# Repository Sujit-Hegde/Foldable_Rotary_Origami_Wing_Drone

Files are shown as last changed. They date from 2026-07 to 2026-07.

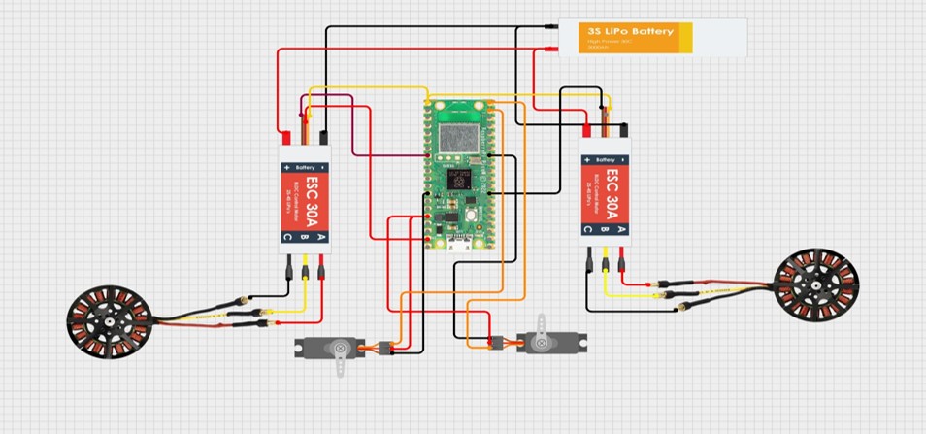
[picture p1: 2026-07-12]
Circuit Diagram.jpg

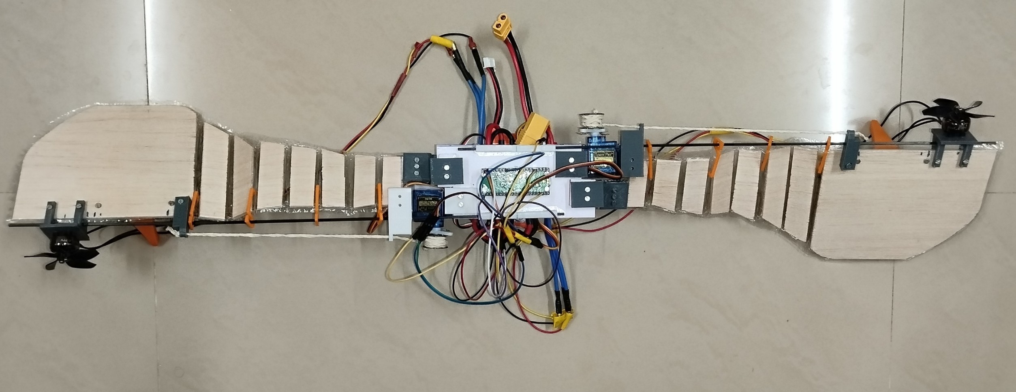
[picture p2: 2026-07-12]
FROW Picture.jpg

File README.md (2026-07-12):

# Foldable Rotary Origami Wing (FROW) Drone

A bio-inspired **Foldable Rotary Origami Wing (FROW) Drone** that combines the energy efficiency of a **monocopter** with an **origami-inspired morphing wing mechanism**. The drone actively changes its wingspan during operation using a servo-driven folding mechanism, enabling it to transition between efficient hovering and compact flight configurations suitable for navigating confined environments.

This project was developed as a **Bachelor of Engineering Final Year Project** in the Department of Electronics and Instrumentation Engineering, **Sri Jayachamarajendra College of Engineering (SJCE), JSS Science and Technology University, Mysuru**.

---

# Project Overview

Conventional quadcopters have a fixed geometry that limits their ability to fly through narrow passages such as pipelines, collapsed structures, and confined industrial environments.

The **Foldable Rotary Origami Wing (FROW) Drone** addresses this limitation by integrating an accordion-style origami wing capable of reducing its wingspan during operation. The platform adopts a **single-actuator monocopter configuration**, producing lift through a rotating wing while maintaining a lightweight and energy-efficient design.

The project combines:

- Bio-inspired aerodynamics
- Origami engineering
- Embedded control
- Wireless web-based control
- Mechanical morphing
- Raspberry Pi Pico W based control

---

# Features

- Active origami wing folding mechanism
- Approximately **40% wingspan reduction**
- Lightweight monocopter platform
- Raspberry Pi Pico W based controller
- Brushless DC motor propulsion
- Servo-controlled folding mechanism
- Wireless control through Wi-Fi
- React.js based dashboard
- Node.js backend server
- Adjustable motor pulse width
- Adjustable motor hold time
- Safe motor ramp-up and ramp-down sequence
- Remote operation through browser

---

# Project Demonstration

The complete web dashboard is deployed on **Vercel**.

### Live Website

https://trial-web-snowy.vercel.app

The dashboard allows users to:

- Turn system ON/OFF
- Fold the wings
- Reset the wings
- Configure maximum ESC pulse
- Configure motor hold time
- Send commands wirelessly to Raspberry Pi Pico W

---

# Repository Structure

```
Foldable_Rotary_Origami_Wing_Drone/
│
├── 3D Design/
│   ├── Servo Holder
│   ├── Wing Holder
│   ├── Guide Track
│   ├── Motor Mount
│   ├── Wing Hanger
│
├── backend/
│   ├── server.js
│   ├── package.json
│   ├── package-lock.json
│   └── .gitignore
│
├── trial-web/
│   ├── public/
│   ├── scripts/
│   ├── src/
│   ├── package.json
│   ├── package-lock.json
│   ├── README.md
│   └── .gitignore
│
├── main.py
│
├── FROW Report.pdf
│
└── README.md
```

---

# Repository Description

## 3D Design

This folder contains all CAD models and 3D printable structural components used in the drone.

The components include:

- Servo Holder
- Wing Holder
- Wing Hanger Supports
- Slider Mechanism
- Guide Track Endcaps
- Motor Holders
- Structural Mounts

These parts were designed to assemble the foldable origami wing mechanism while maintaining structural rigidity during high-speed rotation.

---

## backend

The backend is developed using **Node.js** and serves as the communication bridge between the web dashboard and the Raspberry Pi Pico W.

Functions include:

- Store current drone state
- Receive dashboard commands
- Provide REST API endpoints
- Synchronize motor commands
- Synchronize servo commands

Main file:

```
server.js
```

---

## trial-web

This folder contains the complete frontend application developed using **React.js**.

The dashboard provides:

- Power Toggle
- Fold Button
- Reset Button
- Hold Time Input
- Maximum Pulse Input
- Real-time communication with backend

The frontend is deployed on:

https://trial-web-snowy.vercel.app

---

## main.py

This file contains the **entire Python program executed on the Raspberry Pi Pico W**.

Unlike traditional embedded projects, **no firmware development framework is used**.

The Raspberry Pi Pico W directly executes this Python program to:

- Connect to Wi-Fi
- Read dashboard commands
- Control ESC
- Control Servo Motors
- Execute safe motor ramping
- Execute folding sequence
- Update backend state

Major functionalities include:

- Wi-Fi communication
- HTTP REST requests
- PWM generation
- Servo control
- ESC control
- Safety limits
- Motor ramp-up
- Motor ramp-down
- Automatic backend synchronization

---

## FROW Report.pdf

This document contains the complete technical documentation of the project.

The report describes every stage of development, from concept to prototype testing, including theoretical background, hardware implementation, software architecture, experimental results, and future improvements.

### Contents of the Report

### Chapter 1 – Introduction

Introduces the motivation behind the project, discusses the limitations of conventional UAVs, presents the concept of the Foldable Rotary Origami Wing (FROW) Drone, and explains the objectives, project overview, and report organization.

---

### Chapter 2 – Literature Review

Presents a comprehensive survey of research papers related to:

- Monocopters
- Bio-inspired UAVs
- Morphing drones
- Origami engineering
- Foldable aerial robots

The chapter also compares existing systems, identifies their limitations, and explains how the proposed FROW drone addresses these challenges.

---

### Chapter 3 – Methodology

Describes the complete design methodology of the project, including:

- Project objectives
- Bio-inspired aerodynamic concepts
- Origami engineering principles
- Rotating platform control theory
- System architecture
- Hardware block diagram
- Circuit diagram
- Prototype design
- Performance evaluation metrics

---

### Chapter 4 – Hardware Description

Explains the physical implementation of the drone.

Topics covered include:

- Design specifications
- Material selection
- 3D printed components
- Servo holder
- Wing hanger supports
- Motor mounts
- Guide track endcaps
- Wing holder
- Fabrication parameters
- Hardware integration

This chapter describes the complete construction and assembly of the FROW prototype.

---

### Chapter 5 – Software Description

Describes the complete software architecture of the system.

It includes:

- Dashboard implementation
- User Interface
- Backend communication
- Python control program
- Control logic
- Safety mechanisms
- Wireless communication
- System workflow

The software enables real-time wireless control of the drone through a web browser.

---

### Chapter 6 – Results and Discussion

Presents the experimental evaluation of the developed prototype.

The chapter discusses:

- Ground testing
- Lift-off experiments
- Folding mechanism performance
- Mechanical observations
- Rotational behavior
- Experimental results
- Performance analysis

The obtained results validate the effectiveness of the foldable monocopter concept.

---

### Chapter 7 – Conclusion and Future Work

Summarizes the overall achievements of the project.

This chapter discusses:

- Project conclusions
- Advantages
- Current limitations
- Practical applications
- Future enhancements

Potential future improvements include autonomous navigation, obstacle detection, advanced stabilization algorithms, and improved flight control.

---

The report also contains:

- Abstract
- Acknowledgements
- List of Figures
- List of Tables
- List of Abbreviations
- References
- Appendix

---

# Hardware Used

- Raspberry Pi Pico W - https://robu.in/product/raspberry-pi-pico-w/
- Brushless DC Motor - https://robu.in/product/flywoo-co-brand-nin-1404-v2-dave-c-fpv-fpv-motortitan-4850kv/
- Electronic Speed Controller (ESC) - https://robu.in/product/30a-bldc-esc-electronic-speed-controller/
- Servo Motor - https://robu.in/product/towerpro-sg90-continuous-rotation-360-degree-servo-motor/
- Li-Po Battery - https://robu.in/product/orange-11-1v-1500mah-3s-40c-lipo-battery-pack-xt60-connector/
- Carbon Fiber Rods - https://robu.in/product/pultruded-square-carbon-hollow-fiber-tube-22mmod-1mmid-400mml-2pcs/
- Balsa Wood - https://www.rcdhamaka.com/product/balsa-sheet-2mm-x-100mm-x-1000mm/
- Polymer Lamination Film - https://www.flightmode.co.in/products/transparent-clear-covering-film-1-meter

---

# Software Used

Frontend

- React.js

Backend

- Node.js
- Express.js

Controller

- Python (Raspberry Pi Pico W)

Communication

- HTTP REST API
- JSON

Development Tools

- Thonny (For Python coding)
- Visual Studio Code

---

# Working Principle

1. User opens the web dashboard.
2. Commands are sent to the backend server.
3. Raspberry Pi Pico W periodically fetches the current state.
4. Python program interprets received commands.
5. Servo motors fold or unfold the origami wings.
6. ESC generates PWM signals to control the BLDC motor.
7. Motor speed gradually increases and decreases for safe operation.
8. Backend updates the current drone status.

---

# Future Improvements

- Closed-loop flight stabilization
- IMU integration
- PID-based control
- LiDAR obstacle detection
- Camera-based navigation
- Autonomous flight
- Waypoint navigation
- UDP communication
- Telemetry support
- Mobile application
- Flight data logging

---

# Demo Video

Link - https://drive.google.com/drive/folders/1Tsia0g6oVi0r_j1Qm1odxm1_M7kFNv6A?usp=sharing

---

# Authors

**Sujit Satish Hegde**

Department of Electronics and Instrumentation Engineering

Sri Jayachamarajendra College of Engineering

JSS Science and Technology University

---

**Virupaksha A. Alur**

Department of Electronics and Instrumentation Engineering

Sri Jayachamarajendra College of Engineering

JSS Science and Technology University

---

**Abhishek K. T**

Department of Electronics and Instrumentation Engineering

Sri Jayachamarajendra College of Engineering

JSS Science and Technology University

---

# License

This repository is intended for **academic and educational purposes**.

Feel free to use the project for learning and research while providing appropriate credit to the authors.

---

⭐ If you found this project useful, consider giving this repository a star.

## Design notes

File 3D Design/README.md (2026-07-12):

These are the 3D Design which are required for the Foldable Rotary Origami Wing (Frow) Drone

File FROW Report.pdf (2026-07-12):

### JSS Mahavidyapeetha JSS SCIENCE AND TECHNOLOGY UNIVERSITY SRI JAYCHAMRAJENDRA COLLEGE OF ENGINEERING JSS Technical Institutions’ Campus, Mysuru – 570006

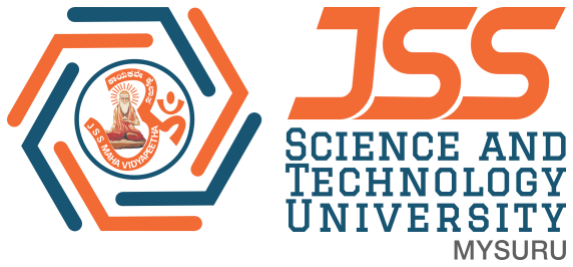
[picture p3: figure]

## FOLDABLE ROTARY ORIGAMI WING (FROW) DRONE

### Thesis submitted in partial fulfillment of curriculum prescribed for the award of the degree of

### BACHELOR OF ENGINEERING

IN

### ELECTRONICS AND INSTRUMENTATION ENGINEERING

by

## Sujit Satish Hegde

(02JST22UEI052)

## Virupaksha A Alur

(02JST22UEI059)

## Abhishek K T

(02JST23UEI401)

### Under the Guidance of

Dr. SUSHMA T
Assistant Professor,

### Department of Electronics and Instrumentation Engineering

SJCE, JSS STU, Mysuru.

DEPARTMENT OF ELECTRONICS AND INSTRUMENTATION ENGINEERING

May 2026

JSS MAHAVIDYAPEETHA
JSS SCIENCE AND TECHNOLOGY UNIVERSITY

## SRI JAYACHAMARAJENDRA COLLEGE OF ENGINEERING

- Constituent College of JSS Science and Technology University
- Approved by A.I.C.T.E
- Governed by the Grant-in-Aid Rules of Government of Karnataka
- NAAC Accredited

## CERTIFICATE

This is to certify that the work entitled “FOLDABLE ROTATRY ORIGAMI WING

(FROW) DRONE” is a bonafied work carried out by Sujit Satish Hegde (02JST22UEI052),

Virupaksha A Alur (02JST22UEI059) and Abhishek K T (02JST23UEI401) in Partial

fulfillment for the award of the Degree of Bachelor of Engineering in Electronics and

Instrumentation of Sri Jayachamarajendra College of Engineering, JSS Science and

Technology University, Mysuru, during the year 2025-26. It is certified that all corrections /

suggestions indicated during CIE have been incorporated in the report. The project report

has been approved as it satisfies the academic requirements in respect of project work

prescribed for the Bachelor of Engineering degree.

Dr. Sushma T
Assistant Professor
Dept. of E&I
SJCE, JSS STU, Mysuru.

Dr. Mallikarjunaswamy M S
Head of the Department
Dept. of E&I
SJCE, JSS STU, Mysuru.
Examiners: 1. |
Date: | 2. |
Place: Mysuru | 3. |

DECLARATION

We hereby declare that the project entitled “Foldable Rotary Origami Wing

(FROW) Drone” has been carried out by us as a part of our undergraduate studies,

under the guidance of Dr. Sushma T, Assistant Professor, Department of

Electronics and Instrumentation, Sri Jayachamarajendra College of Engineering,

JSS Science and Technology University, Mysuru.

This work is submitted in partial fulfilment of the requirements for the award of

the Bachelor’s Degree in Electronics and Instrumentation Engineering at Sri

Jayachamarajendra College of Engineering, JSS Science and Technology

University, Mysuru, during the academic year 2025-26

We further declare that this project work is original and has been carried out

independently by us. The content of this report has not been submitted, either in part or

in full, to any other university or institution for the award of any degree or diploma.

Date:

Place: Mysuru | Sujit Satish Hegde
| 02JST22UEI052

Virupaksha A Alur

02JST22UEI059

Abhishek K T

02JST23UEI401

i

## ABSTRACT

The fast development and miniaturization of electronics have contributed significantly

to the development of MAVs that are applied in vital tasks such as indoor surveillance,

search & rescue missions, and structural inspection operations. However, despite their

high maneuverability, conventional quadrotors are characterized by low power

efficiency owing to small rotor diameters and a large body that cannot fit into enclosed

areas. In addressing this challenge, the present project proposes the use of a FROW

drone, which combines the advantages of a highly efficient rotary wing aircraft design

and the flexibility offered by the origami concept.

Inspired by the movement of the samara seed as well as the ability of birds to fold their

wings while maneuvering through tight spaces, the FROW drone incorporates a

spinning wing for generating lift across the entire wing surface. The key breakthrough

comes from incorporating an accordion-like folding wing system in which the wingspan

can be actively contracted or expanded in mid-flight. This feature permits the drone to

switch between flight modes, from a wider span ideal for hovering to a more compact

form intended for accessing tight passages and pipelines.

The structure of the drone consists of flexible balsa wood pieces joined with sheets of

thin plastic. This allows the wing to maintain structural rigidity during high-speed

rotation while still be able to bend so that the folds can function. An automatic string

reel is used to manipulate the accordion fold pattern, thereby reducing the area occupied

by the aircraft by about 39% to 40% mid-flight. This advantage puts the UAV ahead of

traditional drones which may be less maneuverable.

Moreover, attitude stabilization control has been integrated into the system to mitigate

the unwanted angular rates of motion that result when the moment of inertia of the

aircraft varies with the folding of the wings. Through the use of the internal inertial

sensors, the stability of the UAV is assured despite the drastic changes in the flight

dynamics of the aircraft.

The effectiveness of the drone was tested extensively, with emphasis on its capability

to take off from the ground and demonstrate the mechanical folding process. The results

suggest that the drone is successful in meeting its objective of reducing wingspan while

still having enough lift to fly. The system achieved a flight efficiency of approximately

ii

7.1 g/W, outperforming traditional multirotor drones such as the Crazyflie, which flies

at an average of 4.3 g/W.

In addition to the morphing dynamics, the mechanical construction of the FROW drone

also relies on modularity and economy of materials. Specifically, components such as

balsa wood and carbon fiber are employed in order to build a highly efficient yet

lightweight structure. The particular design of the wing components involves an

accordion-folding design that uses guide rails and hangers to allow the wings to

contract. Hardware in this case is coupled with the Raspberry Pi Pico controller which

collects live readings from a three-axis magnetic field sensor and inertial sensors to

maintain the stability of the device in both vertical and horizontal directions. Through

balancing centrifugal forces produced while rotating and mechanical tensions created

through servos, it is possible to sustain aerodynamic lift while reducing the size of the

wings.

The successful realization of the folding rotary-wing concept is thus a key proof-of-

concept step toward the development of the next wave of transformable aerial robots.

Overcoming the constraints of limited footprints associated with conventional UAVs,

while retaining the energy efficiency of a monocopter, offers great opportunities to

explore new ways of using drones in situations where only small UAVs would fit in.

Utilizing the potential of paper engineering in order to fabricate intricate,

multifunctional geometries enables the creation of robots which are both portable and

deployable on short notice in time-critical situations.

## iii

## ACKNOWLEDGEMENTS

With profound pleasure and immense satisfaction, we submit our project entitled –

"FOLDABLE ROTARY ORIGAMI WING(FROW) DRONE ".

We take the opportunity to express our sincere gratitude to the following persons

without whom this project would not have been possible and whose firm belief in our

capabilities and moral support in bringing out our full potential towards the forefront

has played a major role in each and every step of our endeavor towards success.

We express our deep sense of gratitude to our guide Dr. Sushma T, Assistant Professor,

Department of Electronics and Instrumentation Engineering, Sri Jayachamarajendra

College of Engineering, JSS Science and Technology University, Mysuru for the

valuable help and guidance. We are thankful for the encouragement given in completing

the project.

We would like to express our sincere thanks to our project coordinators Dr. Babu K S,

Ms. Anusha M U, Assistant Professors, Department of Electronics and Instrumentation

Engineering, Sri Jayachamarajendra College of Engineering, JSS Science and

Technology University, Mysuru for assisting us in all the activities involved in

completing the project.

We would like to express our sincere thanks to Dr. Mallikarjunaswamy M S,

Associate Professor and Head, Department of Electronics & Instrumentation

Engineering, Sri Jayachamarajendra College of Engineering, JSS Science and

Technology University. Mysuru, for permitting us to utilize all the facilities of the

department.

We would like to express our sincere thanks to our respected Principal, Dr. C Nataraju

for providing us an excellent academic atmosphere and encouragement in the

university.

We would like to thank Mr. Soorya Swamy Student from Department of Mechanical

Engineering and Aero JC for helping us with the lamination of the wings and the design

of the 3D model. We are also thankful to all the teaching and non-teaching staff

members of our department for their kind cooperation and help.

iv

## CONTENTS

Sl. No. | Content | Page No.
| | Abstract | i
| | Acknowledgement | iii
| | Contents | iv
| | List of Figures | vi
| | List of Tables | vi
| | List of Abbreviations | vii
1. | | INTRODUCTION | 1
| 1.1 | Motivation | 2
| 1.2 | Objectives | 3
| 1.3 | Overview of the Project | 4
| 1.4 | Organization of the Report | 5
2. | | LITERATURE REVIEW | 7
| 2.1 | Comparison of Existing System | 11
3. | | METHODOLOGY | 14
| 3.1 | Objectives | 14
| 3.2 | Bio-Inspired Aerodynamics | 15
| 3.3 | Origami Engineering Principles | 15
| 3.4 | Control Theory for Rotating Platforms | 16
| 3.5 | System Architecture and Design | 17
| 3.6 | Evaluation Metrics | 20
4. | | HARDWARE DESCRIPTION | 21
| 4.1 | Design Specifications and Materials | 21
| 4.2 | Hardware and 3D Components | 22
| 4.3 | 3D-Printed Structural Components | 22
| 4.4 | Fabrication Parameters | 26
| 4.5 | Hardware Integration | 26
5. | | SOFTWARE DESCRIPTION | 27
| 5.1 | Software Implementation and Interfacing | 27
| 5.2 | Dashboard and User Interface | 27
| 5.3 | Control Logic and Safety Features | 29

v

| 5.4 | Control Flow Diagram | 30
| 5.5 | Control Firmware Development | 30
6. | | RESULTS AND DISCUSSION | 32
| 6.1 | Test Results | 32
| 6.2 | Discussion | 34
7. | | CONCLUSION AND FUTURE WORK | 35
| 7.1 | Conclusion | 35
| 7.2 | Advantages | 36
| 7.3 | Limitations | 36
| 7.4 | Applications | 37
| 7.5 | Future Enhancements | 38
| | REFERENCES | 39
| | APPENDIX | 41

vi

## LIST OF FIGURES

Figure No. | Name | Page No.
3.1 | Block Diagram of the Proposed FROW System | 17
3.2 | Circuit Diagram | 18
3.3 | Prototype Design | 19
3.4 | Design Output of FROW | 19
4.1 | Servo Holder | 23
4.2 | Wing Hanger Supports and Slider | 23
4.3 | Leading Edge Motor Mount | 24
4.4 | Guide Track Endcap | 24
4.5 | Wing Holder | 25
4.6 | Leading-Edge Motor Holder | 25
5.1 | Dashboard and User Interface – I | 28
5.2 | Dashboard and User Interface – II | 29
5.3 | Control Flow Diagram | 30
5.4 | Main Logic Code Snippet | 31
6.1 | Unfolded FROW Rotation | 33
6.2 | Folded FROW Rotation | 33

## LIST OF TABLES

Table No. | Name | Page No.
2.1 | Comparison of Existing Systems | 11
4.1 | Fabrication Parameters | 26

## vii

## LIST OF ABBREVIATIONS

Abbreviation | Full Form
UAV | Unmanned Aerial Vehicle
MAV | Micro Aerial Vehicle
FROW | Foldable Rotary Origami Wing
ESC | Electronic Speed Controller
BLDC | Brushless DC
PWM | Pulse Width Modulation
FPV | First Person View
PLA | Polylactic Acid
FDM | Fused Deposition Modeling
GUI | Graphical User Interface
HTTP | Hypertext Transfer Protocol
REST API | Representational State Transfer Application Programming Interface
JSON | JavaScript Object Notation
IMU | Inertial Measurement Unit
GPIO | General Purpose Input/Output
PDB | Power Distribution Board
KV | RPM per Volt Rating of BLDC Motor
PID | Proportional Integral Derivative
UI | User Interface
Li-Po | Lithium Polymer

## CHAPTER 1

## INTRODUCTION

Drones or Unmanned Aerial Vehicles (UAVs) have evolved from specialized devices

used by the military to vital tools for civilians in numerous applications. They are

currently utilized for various purposes, such as mapping the environment, surveillance

in cities, inspecting infrastructure, and conducting rescue missions during emergencies.

Their importance is mainly attributed to their capability of operating in environments

that can be dangerous, distant, or constrained, making them inaccessible to humans.

With an increase in the need for adaptable unmanned aerial robots, studies have

concentrated on improving maneuverability in complex settings.

Even though they are common, the basic design of a multicopter, particularly a

quadcopter, still has fundamental constraints. Quadcopters are highly agile aircraft that

can take off vertically but create thrust using small propellers, which according to

momentum theory, is an inefficient way of generating thrust while hovering as opposed

to large rotor areas. Additionally, traditional drones have a fixed geometric

configuration, meaning that their wingspan and arm span cannot change when in the

air. This limits their ability to fly through confined spaces like collapsed buildings or

pipelines.

A solution for overcoming the limitations discussed above comes from the development

of the Foldable Rotary Origami Wing (FROW) drone, a bio-inspired aerial system. In

this regard, one can point out that the main inspiration is derived from the botanic

structure of the samara seed, also known as a “helicopter seed,” which performs the

process of autorotation to land. The monocopter concept, when a single rotating wing

is used for generating lift across the entire wing surface, allows for the realization of

increased flight efficiency compared to conventional drones with multiple wings. This

increased efficiency, however, will be complemented by the concept of “active

morphology” similar to birds such as Peregrine Falcons, which retract their wings for

fast diving or tight maneuvers.

The distinctive feature of the FROW drone is the use of an innovative folding wing

design similar to an accordion. While the earlier models could fold their wings only

with some external help, the FROW model can fold and unfold the wings independently during flight. The wings are made of light balsa wood panels covered with a thin layer

of plastic sheet to achieve sufficient rigidity during fast spinning and facilitate folding

according to the mountains and valleys. In addition, the folding mechanism helps the

drone achieve up to 40% reduction in overall size in flight.

The control of a rotorcraft that transforms during flight poses an entirely different

challenge to engineers due to the shifting center of mass and moment of inertia caused

by changing shapes in mid-air. In order to achieve stability in flight, the proposed

project adopts a control system composed of a Raspberry Pi Pico controller, together

with a customized attitude stabilization algorithm and a cyclic thrust algorithm. Unlike

the use of a swashplate mechanism, the direction control is done through the use of

pulse modulation on the motor thrusts at specific points within the rotation period.

The scope of this work covers all aspects of the development process of the FROW

drone, including designing the drone in CAD programs and analyzing its structural

properties, extending to the fabrication and testing of the prototype on the ground. The

successful lifting of the drone, and its capability to reduce its wingspan, is considered

a proof of concept for transformable drones that are capable of combining efficiency

and agility without compromising one for the other.

### 1.1 MOTIVATION

The primary inspiration behind the creation of the Foldable Rotary Origami Wing

(FROW) drone is rooted in the pressing requirement for highly adaptable drones that

can fly in challenging environments. Standard drones, especially quadrotors, have a

fixed structure that cannot allow them to move through confined spaces smaller than

the drone’s body frame. In cases where drones are used to perform tasks like search and

rescue missions in rubble or inspect pipelines, there is a practical requirement for the

drone to be able to change its structure while in flight.

In addition, existing drones have a tendency to make compromises between efficiency

and maneuverability. The larger span rotors generate better lift and efficiency but are

hard to navigate around obstacles, whereas smaller drones cannot retain their batteries'

performance or payload. This problem has been solved by nature using various

biological strategies, such as the samara seeds' autorotation to conserve energy and the

birds' wing tucking ability for maneuverability around trees and during rapid descents.

Combining these two biological concepts, this project attempts to develop an aircraft

that takes advantage of both namely, high-efficiency monocopters and high

maneuverability morphing aircraft.

Another important factor which may contribute to conducting this research is the

opportunity to increase the stealth capability of the drone. In the process of

implementing modern surveillance missions, the reduced visibility of the drone may

play a significant role. With the help of folding, the FROW drone can assume a "stealth"

configuration which will ensure its ability to conduct missions without being detected

by the enemy or approaching some potentially dangerous zones. The stability achieved

due to the samara-like autorotation provides an additional safety feature since the

aircraft will always have the ability to land softly despite a complete loss of power.

Lastly, the project is driven by the need for improvement of unconventional flight

control systems. It involves creating a system that will remain stable when both the

moment of inertia and the aerodynamic center are constantly changing. Using a control

system based on Raspberry Pi Pico and implementing cyclic thrust control algorithms,

it will become possible to prove that even a vehicle of an irregular shape can be

successfully managed using readily available standard computer equipment. In the end,

FROW drone will serve as a concept of a new kind of robust MAVs that are capable of

adapting to their surroundings physically.

### 1.2 OBJECTIVES

The main aim of this project is to construct a monocopter aerial vehicle that includes

morphing origami wings able to contract/extend the wingspan mid-flight.

To realize this general aim, the project intends to reach the following particular goals:

- Development of an Accordion Origami Wing: Design a light-weight balsa wood

and thin laminate wing having rigid structure but capable of reducing footprint area by

contracting the wing panels mid-flight.

- Creation of an Active Actuation System: Design an actuator mechanism to control

the contraction and extension of the wing panels during flight using strings operated by

a servo system.

- Application of an Effective Control Architecture: Apply the Raspberry Pi Pico W

microcontroller board to stabilize the drone, interface sensors, and perform shape

change operations without disturbing the balance of rotation.

- Determination of Steady Flight Strategies: Design custom stabilization algorithms

to maintain flight stability and implement cyclic thrust approach to steer the vehicle.

- Flying and Morphing Capability Testing: Perform tests for assessing the flying

ability of the drone by generating enough aerodynamic lift, as well as the capability to

actively morph the wing.

- Maneuvering Performance Verification: Assess the possibility for the drone to fly

in confined spaces where its reduced wingspan is needed.

### 1.3 OVERVIEW OF THE PROJECT

In this project, the complete development of the Foldable Rotary Origami Wing

(FROW) is discussed, which is a micro aerial vehicle capable of having high efficiency

and structure change during flight. The FROW platform is created as a monocopter,

based on the idea of autorotation of samara seeds that use a single rotating wing to

produce lift along the entire wing span. In order to be able to vary the wingspan and

thereby switch between modes of flight with high efficiency and maneuvers, folding

has been incorporated into the design through origami.

The project's workflow will begin with the mechanical design of a wing, which will be

constructed using thin panels made of balsa wood and polymer. The panels will be fitted

together using an origami-inspired foldable structure that will enable folding the wing

down along pre-determined creases. To drive the process of folding the wing down, the

mechanical force will be supplied by the servo-controlled string winding system placed

at the center hub, whereas centrifugal forces will be used to unfold the wing.

The design of the control system involves the use of the Raspberry Pi Pico W

microcontroller. It receives the real-time input from the gyroscope and other inertial

devices and ensures balance within the frame of reference despite the constant rotation.

One important aspect of the software program is that of cyclic control, whereby the

thrust from the motor pulses at certain angles to control the angle of attack for both

pitch and roll of the drone.

The last stage includes hardware integration and experimentation. The drone will be

built using high KV FPV motors, ESCs (electronic speed controllers), and a high

discharge Li-Po battery in order to ensure sufficient weight to thrust ratio.

Experimentation will be carried out to confirm the structural integrity of the folding

operation as well as the performance of the stability algorithms. Through testing, it will

be demonstrated that the drone is capable of lifting itself and reducing its size by about

40%.

### 1.4 ORGANIZATION OF THE REPORT

This report is organized into five comprehensive chapters, each addressing specific

aspects of the project to ensure clarity and logical flow.

Chapter 1 sheds light on the importance of innovative UAV designs and draws attention

toward the significance of bioinspired unmanned aerial robotics in present times. The

chapter discusses the need for developing morphing drones, states the research goals,

gives an introduction to the FROW drone design and explains how the research attempts

to satisfy the demands of flight efficiency and spatial agility.

Chapter 2 focuses on the existing works done on foldable unmanned aerial vehicles and

morphing drones. The chapter highlights the inadequacies in existing quadcopter

designs, origami inspired wings, and different in-flight morphing techniques such as

active morphing using servos and passive morphing through centrifugal forces. The

chapter provides insights into the areas where the current fixed footprint drones fall

short in order to justify the adoption of foldable monocopter drones.

In chapter 3, the overall process adopted throughout the project is discussed in depth.

This includes the mechanical designing of the folding wing panels, the incorporation of

the servo-based folding mechanism, selection of the propulsion system, and designing

the control structure using Raspberry Pi Pico microcontroller. In other words, in this

chapter, we provide the comprehensive discussion on all the building blocks that form

the complete flying device.

In Chapter 4, the process of actual construction of the prototype is outlined. The

software environment along with its stabilization algorithms and cyclic thrust operation

is discussed along with its hardware design. This chapter also describes the process of

testing the prototype on the ground and the performance of the aircraft during its lift-off process. The results pertaining to the mechanical efficiency of the folding wings are

also presented.

Chapter 5 will outline the major accomplishments achieved through this project. The

main accomplishment includes the successful implementation of an active wing folding

rotorcraft. The advantages associated with the system are outlined in terms of flight

efficiency, and its weaknesses, such as the fact that the system is at an early stage of

achieving full control during flight, are also discussed. Further improvements that can

be incorporated into the project include gap detection through LiDAR or camera

technology.

## CHAPTER 2

## LITERATURE REVIEW

A literature survey has been carried out by reviewing how Unmanned Aerial Vehicles

have evolved over time from traditional designs that were based on fixed-wing and

multi-rotor UAVs to designs that are flexible and can adapt to the environment based

on biologically inspired principles. Many recent studies on UAV designs have been

centered on addressing the problem of the "fixed-footprint" nature of the UAVs, which

makes it difficult for traditional drone designs to operate in tight environments such as

disaster areas and even industrial complexes internally. Through the combination of the

use of foldable principles, based on origami designs, and the design principle behind

monocopters, current research has been able to design efficient UAVs that are both agile

and power-efficient.

[1] Bhardwaj, H., Cai, X., Win, L. S. T., & Foong, S. (2023). “Nature-inspired in-

flight foldable rotorcraft.” Bioinspiration & Biomimetics, 18(4), 046012. (https://iopscience.iop.org/article/10.1088/1748-3190/acd739)

Findings: In this paper, an innovative design concept of a mono-copter is introduced.

It includes the ability of active and passive folding of its wings when flying inspired

from the capability of birds to fly through narrow passages as well as perform diving

movements. In this research, two models are presented; the first model (FROW-A) is

designed using the capability of servo motors while the second one (FROW-P) depends

on centrifugal force and spiral springs for passive folding of the wings. As results show,

both models are capable of reducing their footprints by 39% and 69%, respectively. A

cyclic control system is utilized to deal with translational movements using pulses of

motor operations.

[2] Win, S. K. H., Win, L. S. T., Sufiyan, D., & Foong, S. (2021). “Design and

control of the first foldable single-actuator rotary wing micro aerial vehicle.”

Bioinspiration & Biomimetics, 16(6), 066019. (https://iopscience.iop.org/article/10.1088/1748-3190/ac253a)

Findings: This paper describes the process of creation of the F-SAM, which is a

monocopter with a folding semi-rigid wing. It makes use of the principle of centrifugal

force to help it straighten while in motion. The aircraft uses a single thrust unit to

achieve five degrees of freedom by regulating force using many rotations and pulsing the single thrust unit for controlling its motion. This paper points out how efficient

single actuator devices are when used since the flight time achieved was 16 minutes

with a take-off mass of 69g.

[3] Li, M. (2025). “Beyond Conventional Drones: A Review of Unconventional

Rotary-Wing UAV Design.” *Drones*, 9(5), 323. (https://www.mdpi.com/2504-446X/9/5/323)

Findings: This review classifies various non-conventional UAV designs, emphasizing

that the monocopter design system is substantially lighter and consumes less energy

compared to conventional quadcopters. The author further states that the energy

required for hovering decreases with decreasing rotor radius, which makes large-area

single-wing designs superior. Nevertheless, the review highlights the issue of stability

and controllability when there is a change in vehicle shape while flying. Morphology-

dependent control mechanisms are therefore crucial in maintaining control over

changing centers of mass and aerodynamics in morphing air vehicles.

[4] Ishiguro, R., et al. (2023). “Earwig-inspired foldable origami wing for micro

air vehicle gliding.” *Frontiers in Robotics and AI*, 10, 1255666. (https://www.frontiersin.org/journals/robotics-and-ai/articles/10.3389/frobt.2023.1255666/full)

Findings: The current work studies how earwig inspired origami patterns can be used

to produce highly folded wings in MAVs. In the present study, it was found out that

wing area could be shrunk 7 times while folding, which makes highly dense packing

and fast deployment possible. The process of wing production consists of stacking thin

films of polymers and rigid panels, making the wings both flexible and stiff. Although

the research was concerned only with gliders, this work sheds light on an important

issue related to origami hinge longevity under wind pressure.

[5] Shiferaw, Y., et al. (2021). “Design and Implementation of Morphed Multi-

Rotor Vehicles with Real-Time Obstacle Detection and Sensing System.”

*Sensors*, 21(18), 6192. (https://www.mdpi.com/1424-8220/21/18/6192)

Findings: The following is a research paper on the advantages of morphing capabilities

when it comes to navigation for drones, where morphing allows drones to pass through

gaps that cannot be navigated by drones with non-morphing properties. In addition, the

researchers use real-time control algorithms along with sensors in order to adjust the

drones' positions according to any obstacles they encounter during flight. Even though the study was performed using a multi-rotor drone, the conclusions drawn from it can

be applied directly to our drone.

[6] Acar, O., et al. (2025). “Mechanisms and Control Strategies for Morphing

Structures in Quadrotors: A Review and Future Prospects.” *Drones*, 9(9), 663. (https://www.mdpi.com/2504-446X/9/9/663)

Findings: The paper reviews the mechanical and control challenges associated with

morphing aircraft. The authors point out that to have a successful morphing aircraft, it

is important to employ a morphology-aware control scheme that considers the

dynamics of change in the moments of inertia and mass. In this regard, the research

shows that conventional controllers such as PID controllers require online adjustment

or a combination of approaches to ensure stability during dynamic morphing

operations. This is consistent with our design plan that employs a Raspberry Pi Pico

board to manage custom stabilization loops.

[7] Choi, Y., et al. (2025). “Bioinspired Morphing in Aerodynamics and

Hydrodynamics: Engineering Innovations for Aerospace and Renewable Energy.”

*Biomimetics*, 10(7), 427. (https://www.mdpi.com/2313-7673/10/7/427)

Findings: This paper discusses the evolution in the field of bio-inspired morphing

structures from traditional to more advanced methods, with specific emphasis on the

shift from rigid aerodynamics to flexible structures. According to this study, the

morphing surfaces that have been designed based on the characteristics of feathers in

bird wings can offer better drag reduction and lift augmentation than traditional fixed-

geometry wings. It also stresses the use of smart materials and mechanisms like the

folding pattern adopted in our FROW drone to ensure smooth changes in the flight

profile. For mini rotorcraft, it is essential that their ability to change form helps maintain

their efficiency at different Reynolds numbers.

[8] Johnson, K., et al. (2023). “Solar-powered shape-changing origami

microfliers.” *Science Robotics*, 8(77). (https://www.researchgate.net/publication/391861488_Adaptive_continuous-shape-changing_solar-powered_microfliers)

Findings: The current research illustrates the viability of self-deployment of origami

designs in micro aerial vehicles. In this research, light material and thin film electronics

are employed to make flying objects able to modify their patterns of falling by changing

their shapes in mid-air. One of the findings that came out of this research is that the

energy consumption is very important when it comes to mechanisms that enable changing the shape. Natural forces like centrifugal force, which we have employed in

our research, play a big role in reducing the burden of energy consumption from the

battery.

[9] Tothong, P., et al. (2022). “Design and Flight Control of a Symmetrically

Morphing Quadrotor.” *IEEE Transactions on Robotics*, 38(5), 2680–2695. (https://www.researchgate.net/publication/353392743_Design_Modeling_and_Control_of_a_Novel_Morphing_Quadrotor)

Findings: The proposed work introduces a quadrotor that is capable of symmetrically

scaling its footprint in mid-air by means of linear actuators. The authors emphasize that

due to changing characteristics associated with the mass and moment of inertia, the

control system must adapt to the changes in the dynamics of the platform in order to

ensure stability. As a result, the authors note that smaller footprints with folded legs are

more agile when it comes to maneuvering in constrained environments, while larger

footprints with extended legs are more resilient to external disturbances such as wind

or turbulence.

[10] Ishiguro, R., et al. (2021). “A robotic wing inspired by the earwig’s fan-like

folding mechanism.” *Frontiers in Robotics and AI*, 8, 732588. (https://www.frontiersin.org/journals/robotics-and-ai/articles/10.3389/frobt.2023.1255666/full)

Findings: The current research paper concentrates on the engineering of such folding

mechanisms with regard to the wings of earwigs resembling fans. It has been shown

that such folding mechanisms possess good capability to achieve a high degree of area

reduction (sevenfold), yet retain high rigidity when completely unfolded. Laminated

composites were noted as an important material option to manufacture resilient "living

hinges" that can withstand several thousand bending cycles. Such information is

important to justify the choice of balsa and film lamination in our FROW wing.

The literature survey reveals that bio-inspired morphing UAVs provide improved

maneuverability, compactness, and energy efficiency compared to conventional

quadrotors. Monocopter-based systems combined with origami-inspired folding

mechanisms enable significant footprint reduction while maintaining aerodynamic

performance during flight. The studies also highlight the importance of lightweight

materials and adaptive stabilization algorithms to manage changes in moment of inertia

during morphing. Overall, the survey concludes that origami-inspired monocopter

UAVs offer a promising solution for compact, energy-efficient, and adaptable aerial

platforms suitable for confined environments.

### 2.1 COMPARISON OF EXISTING SYSTEMS

Table 2.1 Comparison of Existing Systems

Reference & Overview | Identified Limitations | How Our Project Overcame This Limitation
[1] Bhardwaj, H., Cai, X., Win, L. S. T., & Foong, S. (2023). “Nature-inspired in-flight foldable rotorcraft.” Bioinspiration & Biomimetics, 18(4), 046012. Primary Blueprint: Proposes active (FROW-A) and passive (FROW-P) wing-folding monocopters achieving ~40% and ~69% footprint reductions. | Replicating the physical design requires precise manual fabrication, lightweight compliance, and robust real-time firmware to execute the complex control laws. | We successfully fabricated the physical FROW-A replica using 2mm balsa wood panels and polymer-film living hinges, utilizing a Raspberry Pi Pico W programmed in MicroPython to manage the active spool tensioning sequence.
[2] Win, S. K. H., Win, L. S. T., Sufiyan, D., & Foong, S. (2021). “Design and control of the first foldable single-actuator rotary wing micro aerial vehicle.” *Bioinspiration & Biomimetics*, 16(6), 066019. F-SAM Monocopter: A single-actuator vehicle with a semi-rigid folding wing that depends on centrifugal force to open. | The folding mechanism is purely passive and limited to pre-flight storage; it lacks active mid-flight shape-reconfiguration and control. | We implemented the active morphing (FROW-A) scheme. By adding a micro-servo and thread-guiding spool, our platform can actively fold and unfold its wingspan in mid-air to navigate tight gaps.
[3] Li, M. (2025). “Beyond Conventional Drones: A Review of Unconventional Rotary-Wing UAV Design.” *Drones*, 9(5), 323. Unconventional UAV Review: Proves monocopters are highly power-efficient but highlights major stability challenges when geometry changes in-flight. | Explains the physical mathematics of shifting aerodynamic centers and inertia but does not supply a validated, low-cost physical hardware solution. | We embedded safety-clamping algorithms and a 0.05-step ESC ramping sequence into our MicroPython firmware, preventing motor-induced wobbling (precession) during morphing.

[4] Ishiguro, R., et al. (2023). “Earwig-inspired foldable origami wing for micro air vehicle gliding.” *Frontiers in Robotics and AI*, 10, 1255666. Earwig Origami Glider: Achieves extreme 7x area-reduction using laminated polymer films and rigid origami panels for gliding. | Designed purely for passive gliding; the compliant folds were never tested under the intense, continuous centrifugal forces of powered rotation. | We reinforced our laminated balsa wood panels with custom, 3D-printed orange leading-edge caps and slider hangers, allowing the hinges to survive sustained rotational speeds of 54 rad/s.
[5] Shiferaw, Y., et al. (2021). “Design and Implementation of Morphed Multi-Rotor Vehicles with Real-Time Obstacle Detection and Sensing System.” *Sensors*, 21(18), 6192. Morphed Multi-Rotors: Employs real-time obstacle sensors to morph multi-rotor shapes for gap traversal. | Multi-rotor platforms require multiple motor units and linear actuators, which drastically increases physical weight, system cost, and battery drain. | We used the single-actuator monocopter layout. It generates high lift (7.1 g/W) using only one brushless motor and a single micro-servo for folding, keeping the total takeoff weight under 69g.
[6] Acar, O., et al. (2025). “Mechanisms and Control Strategies for Morphing Structures in Quadrotors: A Review and Future Prospects.” *Drones*, 9(9), 663. Morphing Quadrotor Control: Emphasizes that shifting moments of inertia make traditional PID controllers unstable, requiring complex, adaptive code. | Focuses on heavy, complex mathematical simulations for quadrotors without a simple, accessible embedded platform implementation. | We developed a lightweight MicroPython-based architecture on the Raspberry Pi Pico W. This syncs with a web dashboard, allowing the operator to safely test and trigger transitions while the onboard code manages motor ramp speeds.
[7] Choi, Y., et al. (2025). “Bioinspired Morphing in Aerodynamics and Hydrodynamics: Engineering Innovations for Aerospace | Relies on conceptual designs and large-scale wind tunnel studies, with minimal data on micro-scale self-rotating structures. | We fabricated a micro-scale samara-inspired wing. Experimental testing validated that our bio-inspired prototype achieves a high flight efficiency

and Renewable Energy.” *Biomimetics*, 10(7), 427. Bioinspired Aerodynamics: Proves that morphing surfaces reduce drag and optimize lift across varying Reynolds numbers, mimicking bird wings. | | of 7.1 g/W, validating these theories on a micro-UAV.
[8] Johnson, K., et al. (2023). “Solar-powered shape-changing origami microfliers.” *Science Robotics*, 8(77). Origami Microfliers: Uses lightweight self-deploying origami sheets that exploit descent wind to change shape with minimal power. | The scale of the microfliers is too small to carry functional onboard microcontrollers, batteries, or active propulsion systems. | We scaled up the design using a 1500mAh 3S Li-Po battery. We leveraged centrifugal force for passive wing expansion, reserving electrical power solely for active wing-folding and lift.
[9] Tothong, P., et al. (2022). “Design and Flight Control of a Symmetrically Morphing Quadrotor.” *IEEE Transactions on Robotics*, 38(5), 2680–2695. Symmetrically Morphing Quadrotor: Scales its footprint using linear actuators, proving that folded states boost agility while expanded states reject wind. | Symmetrical linear scaling mechanisms add severe weight penalties, which drastically reduces flight endurance. | We replaced heavy linear actuators with a lightweight tensile-cable mechanism. Our micro-servo winds a custom spool to contract the wing, minimizing weight while retaining the advantages of dual-footprint flight.
[10] Ishiguro, R., et al. (2021). “A robotic wing inspired by the earwig’s fan-like folding mechanism.” *Frontiers in Robotics and AI*, 8, 732588. Earwig Fan-Folding: Explores highly compact fan-folding origami patterns with resilient, laminated composite joints. | The complex, multi-axial non-linear folds are incredibly difficult to align and manually fabricate reliably at a student scale. | We simplified the design to an accordion-style folding wing and integrated 3D-printed hinges. This eliminated complex manual fold alignment while maintaining the target 40% reduction in wingspan.

## CHAPTER 3

## METHODOLOGY

The Foldable Rotary Origami Wing (FROW) drone marks an important transition

within the field of aerial robotics, which has shifted from geometrical systems to more

adaptive, nature-inspired designs. With the integration of the efficient mechanism of

monocopter design with the folding ability of origami, FROW aims to tackle one of the

most fundamental challenges in flight – endurance versus maneuverability.

In order to understand the basic concept behind the FROW drone, it is necessary to

familiarize oneself with the fundamentals of this technology, which include the

following three components: biomimicry of flight dynamics, origami technology, and

adaptiveness. These concepts will enable us to better comprehend the mechanics behind

maintaining stability with changing geometry of the wing in-flight.

### 3.1 OBJECTIVES

The primary objective of the Foldable Rotary Origami Wing (FROW) drone is to

develop a bio-inspired aerial platform capable of adapting its physical structure during

flight. The system aims to combine the high aerodynamic efficiency of a monocopter

with the maneuverability advantages of an origami-based morphing mechanism. The

following objectives were identified to achieve the desired functionality and flight

performance:

- Active In-Flight Wingspan Adjustment: Construct an active device that can adjust

the wingspan of the drone in-flight by contracting or extending it. This ensures that the

drone will have both the cruising and folded mode in-flight.

- Origami-inspired Engineering Application: Create a light-weight, accordion-like

wing structure that can sustain very high rigidity at high rotational speeds while still

being flexible enough to collapse mechanically.

- High Efficiency Monocopter Design: Use the one-motor rotating wing concept for

improved energy efficiency over conventional multi-rotor systems. The objective is to

create maximum flight time by creating lift throughout the wing’s surface.

- Morphing Stabilization Control: Implement a controller that stabilizes the drone

while undergoing morphing maneuvers using the Raspberry Pi Pico. This will dampen

the precession motion of the drone while dynamically compensating for any variations

in its moment of inertia.

- High-Speed Freefall without Actuators: In the passive system, implement a high-

speed descent mechanism by gradually decreasing the angular velocity of the drone and

allowing the mechanical springs to fold the wings, similar to how predators dive for

their prey.

### 3.2 BIO-INSPIRED AERODYNAMICS

The FROW drone draws its primary aerodynamic inspiration from two distinct natural

phenomena: the samara seed and the tucking maneuvers of predatory birds.

### 3.2.1 Samara-Inspired Autorotation

The concept behind the monocopter is the mode of flight employed by samaras in

nature, whereby a single wing is used to create lift through rotation.

- Principles of Momentum Theory: The efficiency of hovering increases with

decreasing rotor size; hence, a larger rotating wing is automatically more efficient than

small propeller blades found in multicopters.

- Passive Stability: The location of the CG in relation to the aerodynamic center of the

wing ensures stability during flight.

### 3.2.2 Active Bird-Like Morphology

Whereas samara seeds offer efficiency, birds such as the Peregrine Falcon showcase

agility through wing folding for tight spaces or increased dive velocities. This can be

implemented in the UAV design using active morphology to change its Reynolds

number and moments of inertia as per flight requirements.

### 3.3 ORIGAMI ENGINEERING PRINCIPLES

Origami can form the mathematical and mechanical framework for the design of

lightweight yet stiff deployable structures.

### 3.3.1 Accordion-Style Folding

The FROW drone adopts an accordion folding technique, enabling the wings to contract

linearly within their spanwise direction.

- Mountain and Valley Folds: Pre-existing fold lines enable the contraction of the wing

sections without any contact with the guide rails.

- Area Reduction Ratio: The folding system enables the wings to reduce their

wingspan by up to 40% active folding and 69% passive folding, thereby minimizing

the collision area of the drone.

### 3.3.2 Materials and Compliance

For the realization of such folds without bulky mechanical hinges, the design involves:

- Panel Construction of Balsa Wood: Necessary for sufficient airfoil stiffness to cope

with aerodynamic lift forces.

- Layering of Polymer Material: The “living hinge” material necessary for sufficient

tension during repeated foldings.

### 3.4 CONTROL THEORY FOR ROTATING PLATFORMS

Controlling a monocopter is theoretically more complex than controlling a quadrotor

because the entire body is in a state of constant rotation.

### 3.4.1 Cyclic Control Strategy

Unlike traditional helicopters that utilize mechanical swashplate control for tilting rotor

blades, the FROW drone employs motor thrust pulsing.

- Thrust Pulses: The thrust of the motor is varied, either incremented to T0 + Tamp or

decremented to T0 - Tamp, at an angular orientation γz in each cycle.

- Lift Difference: As a result, there is a difference in lift in the rotating frame causing

tilting motion of the drone.

### 3.4.2 Attitude Stabilization

In-flight morphing alters the mass balance of the vehicle, which may cause unstable

precession or “wobble”.

- Proportional Stabilizer: An angular velocity feedback loop (Ωx, Ωy) stabilizer is

employed to suppress such oscillations.

- Moment of Inertia Adjustment: The control gains of the Raspberry Pi Pico system

will have to adjust depending on wingspan deviation (Δx).

### 3.5 SYSTEM ARCHITECTURE AND DESIGN

The design architecture of the Foldable Rotary Origami Wing (FROW) drone is divided

into its logical operational flow and its physical electronic interface. This section details

the high-level block diagram, the intricate circuit design, and the visual representation

of the fabricated prototype.

### 3.5.1 Block Diagram of the Proposed FROW System

The hierarchical system begins with power delivery from a high-discharge Li-Po

battery to the Raspberry Pi Pico W microcontroller. The Pico W functions as the

primary controller, regulating two different output channels, as shown in Figure 3.1.

- Wing Folding Mechanism: PWM signal for the servo motors controlling the origami

folding wings.

- Lift Rotational Motor Control: PWM signal for the ESCs controlling the brushless

DC motors and propellers.

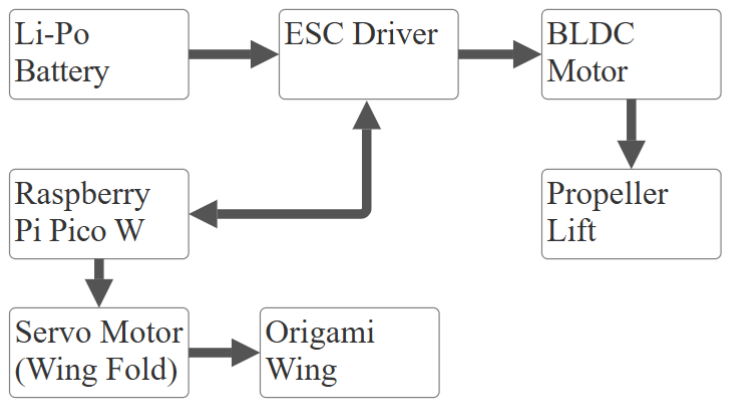
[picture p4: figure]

Figure 3.1: Block Diagram of the Proposed FROW System

The block diagram represents the overall hardware working flow of the Foldable Rotary

Origami Wing (FROW) drone system, illustrating the interaction between the power

source, control unit, propulsion system, and morphing wing mechanism. The Li-Po

battery supplies electrical power to the ESC driver, which regulates the operation of the

BLDC motor responsible for generating rotational lift through the propeller system.

Simultaneously, the Raspberry Pi Pico W generates control signals for both the

propulsion and wing-folding subsystems, enabling coordinated flight operation and

structural morphing during runtime. The servo-controlled origami wing mechanism

allows the drone to dynamically alter its physical footprint while maintaining stable

rotational motion.

### 3.5.2 Electrical Circuit Design and Connections

The electrical circuitry describes the specific connections required to achieve stability

within the rotating frame of the drone. The Raspberry Pi Pico W is interfaced with

various hardware components, as illustrated in Figure 3.2.

- ESC Configuration: Through the GPIO ports for accurate control over the motor

speeds.

- Servo Motors: Connected in tandem to facilitate the folding in of the wings, ensuring

the center of gravity (CG) stays steady.

- Power Control: Either a built-in buck converter or PDB (Power Distribution Board)

used for reducing the battery voltage for the microcontroller while supplying

unregulated voltage for the FPV motors.

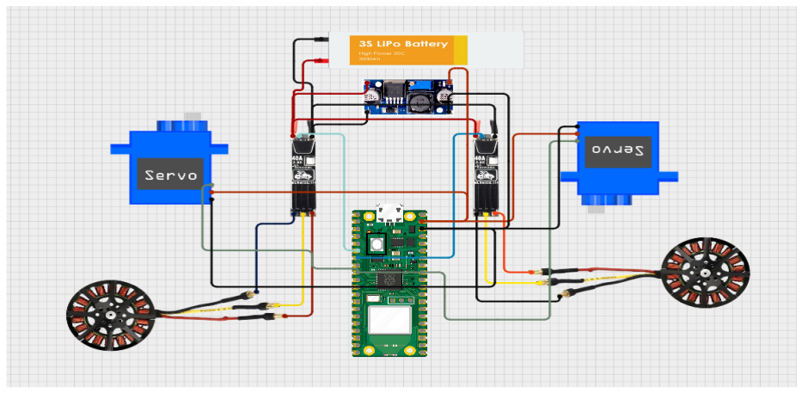
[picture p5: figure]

Figure 3.2: Circuit Diagram

### 3.5.3 Visual Representation of Prototype

The progression from conceptual design to physical prototype construction is

represented through CAD modelling and prototype fabrication, as shown in Figure 3.3.

- Designing by CAD Modeling: This includes a full-fledged model by SolidWorks

CAD which showcases the skeleton structure, such as the carbon fiber guiding tracks

and hub for Raspberry Pi Pico.

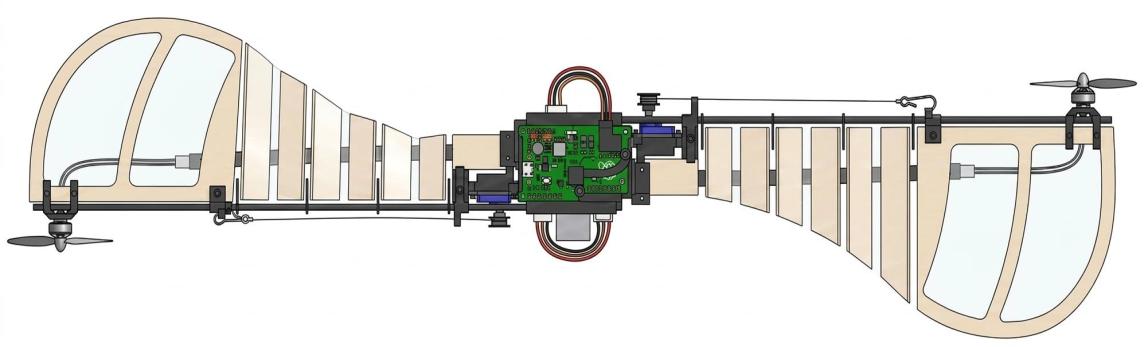
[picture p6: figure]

Figure 3.3: Prototype Design

- Physical Prototype Construction: The fabricated prototype consists of balsa wood

panels covered with a transparent protective film and demonstrates a wingspan

reduction from 75 cm to 45 cm, achieving approximately 40% folding efficiency, as

shown in Figure 3.4.

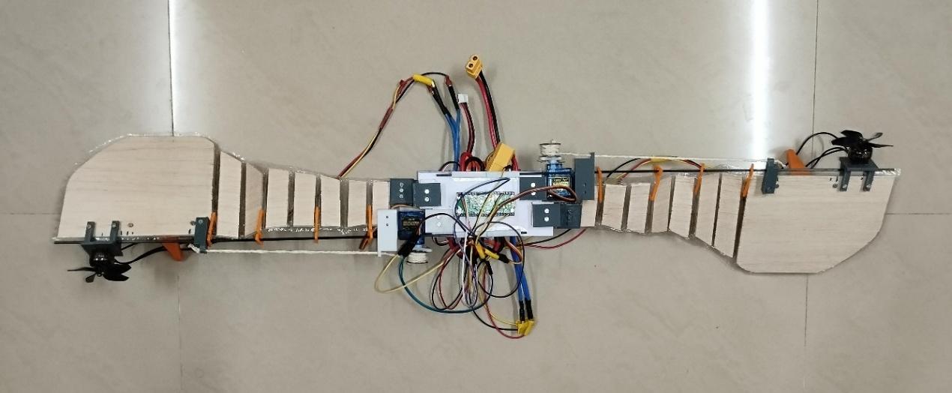
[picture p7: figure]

Figure 3.4: Design Output of FROW

### 3.6 EVALUATION METRICS

To evaluate the drone’s theoretical and physical performance, several important

performance metrics were considered throughout the testing and analysis phase.

These metrics help in assessing the aerodynamic efficiency, morphing capability,

structural stability, and overall operational effectiveness of the Foldable Rotary

Origami Wing (FROW) drone under different flight conditions.

- Flight Efficiency (g/W): The ratio of lift generated to the power consumed,

compared against traditional multicopter benchmarks.

- Footprint Reduction Percentage: Measured as
original length − folded length
original length | ∗ 100
- Rotational Stability: Analyzed via IMU data to measure the decay rate of the

precession circle after a morphing command is executed.

## CHAPTER 4

## HARDWARE DESCRIPTION

The hardware setup of the Foldable Rotary Origami Wing (FROW) drone is an

innovative combination of bio-engineering inspired structures along with highly

efficient electronic devices that ensure the transition from theory to practice. The main

problem in the construction of the device lies in balancing the intense centrifugal forces

acting upon the drone during the process of rotation with the flexible properties

necessary for in-flight morphing. This part describes in detail the process of choosing

appropriate lightweight materials, including balsa wood and carbon fiber, as well as

custom designed 3D-printed elements, such as hinges and motor mounts, which make

up the body of the drone. Through focusing on Raspberry Pi Pico W as the core element

along with high-efficiency propulsion through a single actuator, the hardware is built to

confirm the possibility of providing adequate lift (7.1 g/W), while simultaneously

receiving wireless commands to change its wingspan from 75 cm to 45 cm.

### 4.1 DESIGN SPECIFICATIONS AND MATERIALS

In order to achieve a combination of low weight and sufficient toughness to withstand

centrifugal forces at high speed, appropriate material specifications were required:

- Wing Panels: Balsa wood was chosen with a thickness of 1.5mm owing to its high

strength-to-weight ratio.

- Hinges and Lamination: A thin layer of 0.1mm thick polyethylene was laminated on

top of the balsa wood, thus forming "living hinges" which allow an accordion-style

folding.

- Main Body: A central body composed of 3D-printed PLA along with carbon fiber

rods was used to contain the electronics and act as a rigid pivot point for rotation.

- Actuation Line: For the wing folding actuation, a strong braided Spectra line is used.

### 4.2 HARDWARE AND 3D PRINTED COMPONENTS

The mechanical and physical design of the FROW drone includes several custom 3D-

printed hardware components created using SolidWorks to ensure proper orientation.

- Servo Holding Slanted Mount: This is a custom slanted mount for securing the

micro-servo in the optimum position for pulling the wing contraction string to prevent

any form of mechanical binding.

- Motor Holder: A light and rigid mounting system for attaching the BLDC motor on

the leading wing edge to allowing it to maintain the required tilt angle to produce

rotational torque.

- Hinge System Update: An advanced living hinge design used to attach the balsa

panels to facilitate smooth accordion folding on the carbon fiber rail track system.

- Wing Holder & Stand: These components act as an interface between the main body

and foldable wing sections to ensure that the wings stay aligned during rotation.

- U-Pin Holder: A special clip mechanism used for securing the guide tracks and carbon

fiber rods to the central body of the FROW drone.

- Carbon Fiber Stopper: A precisely designed stopper positioned on either end of the

guide tracks for limiting the wingspan to a maximum of 75cm.

4.3 3D-PRINTED STRUCTURAL COMPONENTS

To achieve the complex folding and rotating requirements of the project, the following

components were modelled and printed using PLA material:

- Servo Holder: The servo holder is designed to securely mount the micro-servo

motor near the central hub of the drone. It maintains proper alignment of the

servo shaft with the folding spool mechanism, ensuring smooth and accurate

wing morphing during operation, as shown in Figure 4.1.

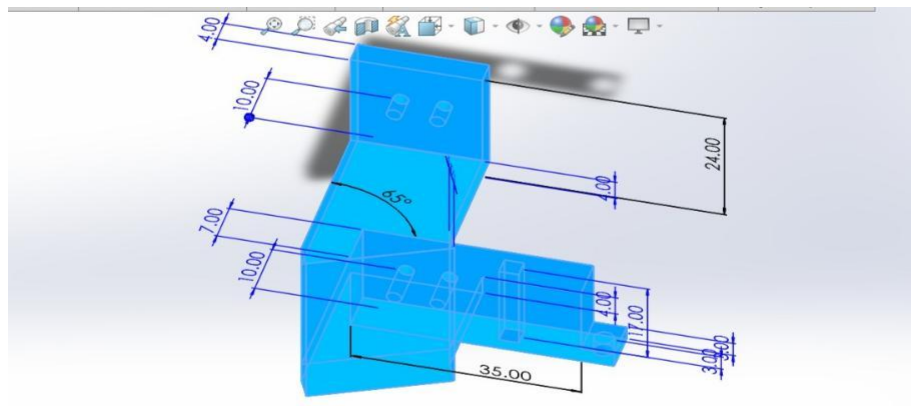
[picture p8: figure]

Figure 4.1: Servo Holder

- Wing Hanger Supports & Sliders: The wing hanger supports and sliders are

attached to the balsa wood wing panels and are designed to slide smoothly along

the carbon fiber guide tracks, ensuring linear accordion folding without binding

during high-speed rotation, as shown in Figure 4.2.

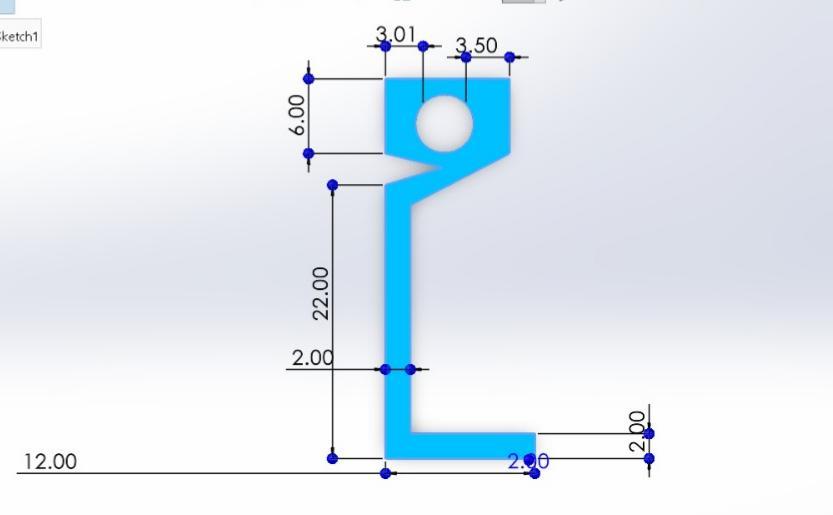
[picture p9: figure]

Figure 4.2: Wing Hanger Supports and Slider

- Leading Edge Motor Mounts: The aerodynamically profiled mounts securely

attach the brushless DC motors to the wing tip and provide the required tilt angle

to generate the initial rotational torque, as shown in Figure 4.3.

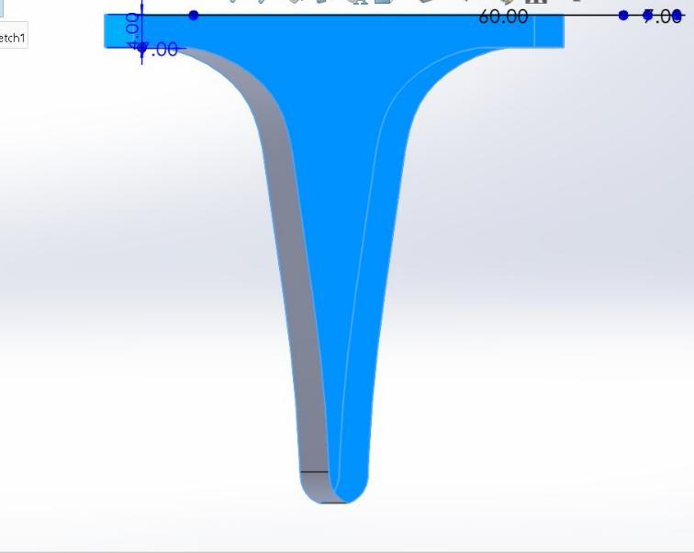
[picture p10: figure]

Figure 4.3: Leading Edge Motor Mount

- Guide Track Endcaps: The guide track endcaps are used to secure the carbon

fiber rods to the central hub and provide a limit stop when the wing panels reach

their fully expanded state of 735 mm, as shown in Figure 4.4.

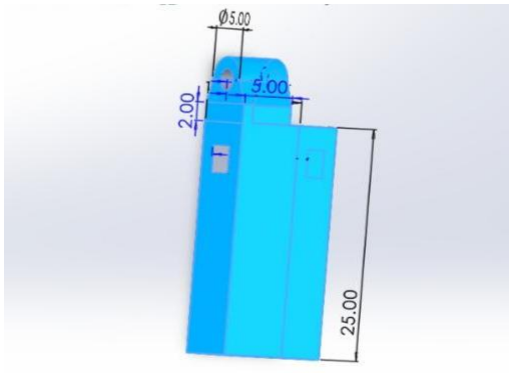
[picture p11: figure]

Figure 4.4: Guide Track Endcap

- Wing Holder: The wing holder is designed to support and secure the entire

origami wing structure to the central framework of the drone. It maintains

structural stability during high-speed rotation while allowing smooth folding

and unfolding motion, as shown in Figure 4.5.

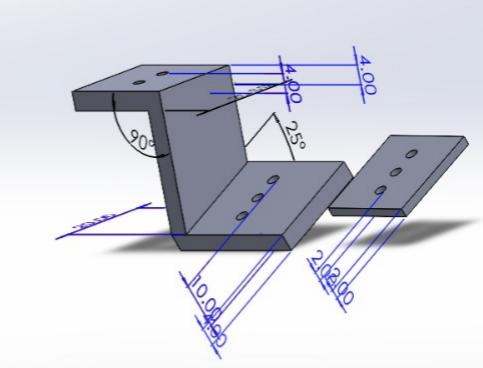
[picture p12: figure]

Figure 4.5: Wing Holder

- Leading-Edge Motor Holder: The leading-edge motor holders mounted at the

wing tips securely house the high-KV FPV motors and are designed with a

specific offset angle to maintain the required rotational torque for monocopter

flight, as shown in Figure 4.6.

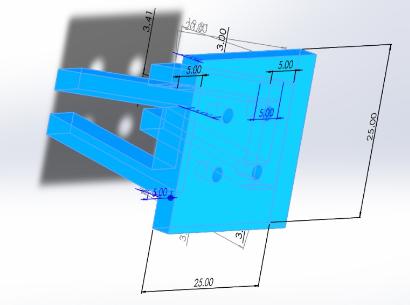
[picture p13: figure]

Figure 4.6: Leading-Edge Motor Holder

### 4.4 FABRICATION PARAMETERS

All components were fabricated using Fused Deposition Modeling (FDM) with specific

technical parameters selected to ensure structural durability and reliability, as listed in

Table 4.1.

Table 4.1 Fabrication Parameters

Parameter | Value/Setting
Material | PLA (High Toughness)
Infill Density | 40% (Tri-Hexagonal for strength)
Layer Height | 0.2 mm
Wall Count | 3 Layers
Printing Temperature | 215°C

### 4.5 HARDWARE INTEGRATION

The hardware assembly followed a modular approach to allow for easy troubleshooting:

- Propulsion System: A 4850 KV brushless motor was mounted at the wing's

leading edge. This motor was paired with a 30A ESC (Electronic Speed

Controller) to handle high-current pulses during cyclic control.

- Control Unit: The Raspberry Pi Pico W was mounted at the center of rotation.

To minimize wiring complexity and weight.

- Power Supply: A 3S (11.1V) 1500mAh Li-Po battery was secured at the hub,

balanced carefully to ensure the center of gravity (CG) remained aligned with

the rotational axis.

- Folding Mechanism: A micro-servo with a custom-designed 3D-printed spool

was integrated to manage the wing's effective length (ℓeff).

## CHAPTER 5

## SOFTWARE DESCRIPTION

The FROW drone utilizes a multi-tier software architecture consisting of a React-based

web dashboard, a Node.js backend, and MicroPython firmware running on the

Raspberry Pi Pico W. This setup allows for wireless control and real-time monitoring

of the drone's power, wing state, and propulsion systems.

### 5.1 SOFTWARE IMPLEMENTATION AND INTERFACING

To ensure the system operates reliably with minimal latency, the following software

stack was implemented:

- Firmware (MicroPython): The Raspberry Pi Pico W runs MicroPython,

utilizing libraries such as network for WiFi connectivity, requests for HTTP

communication, and machine.PWM for precise control of servos and ESCs.

- Backend (Node.js/Render): A cloud-based backend handles the state

management of the drone. It receives commands from the frontend and serves a

JSON state to the Pico W.

- Frontend (React/Vercel): A responsive web dashboard provides a graphical

user interface (GUI) for the operator. It allows for toggling power, triggering

the wing fold, and setting motor hold times.

- Communication Protocol: HTTP REST API is used for data exchange, with

the Pico W performing a GET request to /state every 500ms to fetch the latest

commands.

### 5.2 DASHBOARD AND USER INTERFACE (UI)

The frontend hosted at trial-web-snowy.vercel.app serves as the main control interface

for the Foldable Rotary Origami Wing (FROW) drone. The web dashboard was

developed using React.js with a simple and user-friendly interface to enable safe and

reliable wireless control of the drone through WiFi communication, as shown in Figures

5.1 and 5.2 respectively.

- Power Toggle: A global master switch is provided to enable or disable the entire

system remotely. When turned OFF, the firmware immediately stops motor activity by

returning the ESC to the minimum safe throttle value.

- Servo Control: The dashboard includes “FOLD” and “RESET” buttons to control the

origami wing mechanism. When “FOLD” is triggered, the Pico W generates PWM

signals to the servo motors, causing the wings to contract into a compact configuration.

- Motor Parameters: The interface allows the operator to set the “Hold Time” and

“Max Pulse” values for the BLDC motor. Hold Time controls the duration of high-

speed rotation, while Max Pulse determines the thrust intensity by adjusting the PWM

signal sent to the ESC.

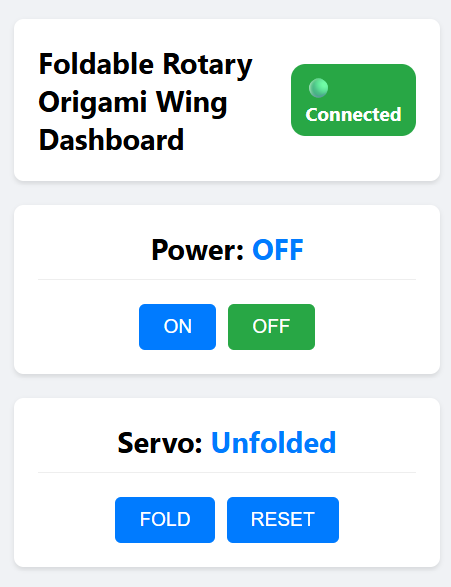
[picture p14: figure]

Figure 5.1: Dashboard and User Interface - I (UI)

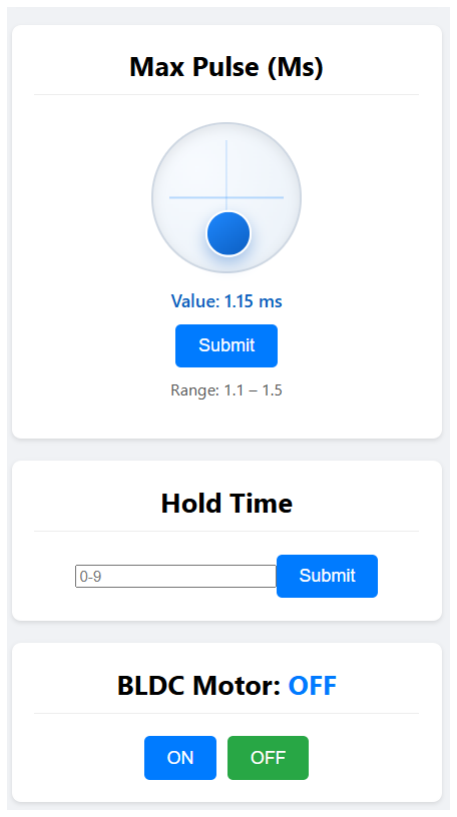
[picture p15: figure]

Figure 5.2: Dashboard and User Interface - II (UI)

### 5.3 CONTROL LOGIC AND SAFETY FEATURES

The MicroPython firmware includes several safety and operational logic blocks:

- Safety Clamping: To prevent motor or ESC damage, the firmware strictly

clamps the motor pulse width between 1.1 ms and 1.5 ms.

- Ramp-Up/Down Logic: To maintain rotational stability and protect the battery

from sudden current spikes, the motor does not jump to high speeds. Instead, it

follows a 0.05-step increment ramp-up and ramp-down sequence.

- State Reset: Once a "FOLD" command is successfully executed, the Pico W

sends a POST request back to the backend to reset the servo command,

preventing redundant operations.

### 5.4 CONTROL FLOW DIAGRAM

The interaction between the user and the hardware follows a sequential flow to ensure

that the drone executes only confirmed commands, as illustrated in Figure 5.3.

- User Action: The user clicks "FOLD" on the Vercel dashboard.
- API Update: The React app sends an HTTP POST to the Render backend,

updating the state to servo: "FOLD".

- Pico Fetch: The Pico W, which polls every 0.5 s, detects the new state.
- Hardware Execution: The Pico W generates PWM signals to the servos (1.3ms

followed by 1.5ms) to contract the wing.

- Completion: The Pico W notifies the backend that the task is finished and

garbage collection (gc.collect()) is run to keep memory usage low.

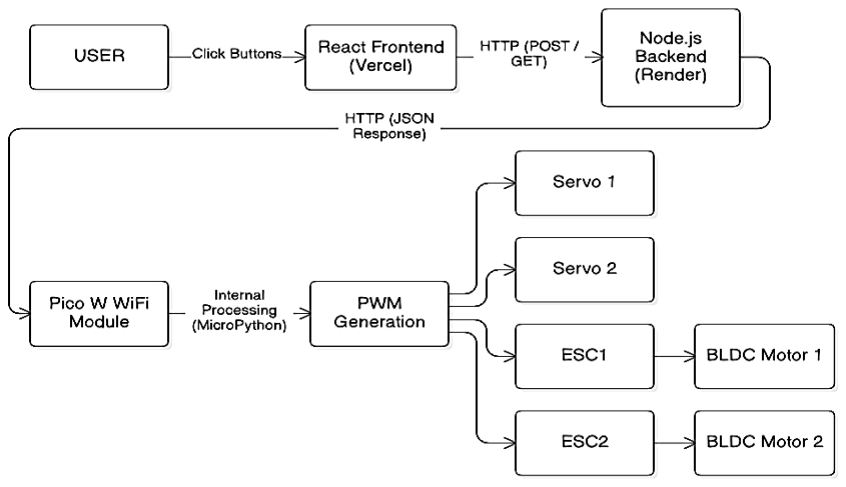
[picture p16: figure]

Figure 5.3: Control Flow Diagram

### 5.5 CONTROL FIRMWARE DEVELOPMENT

The control logic was developed in MicroPython to leverage the Raspberry Pi Pico W's

dual-core architecture and built-in WiFi capabilities. The firmware is responsible for

three primary tasks: maintaining a persistent connection to the control dashboard,

processing incoming JSON state data, and generating high-resolution PWM signals for

the flight actuators.

The following code snippet illustrates the core execution loop, including the safety-

critical motor ramping sequence:

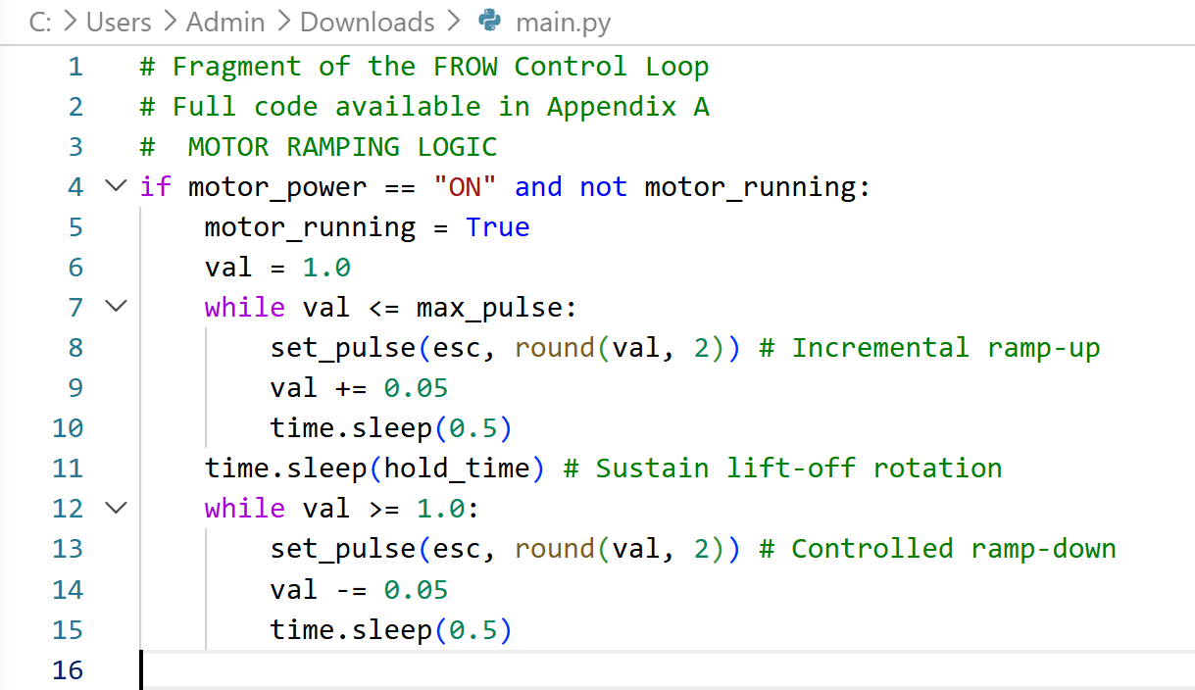
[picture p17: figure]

Figure 5.4: Main Logic Code Snippet

## CHAPTER 6

## RESULTS AND DISCUSSION

This chapter presents the results obtained from the implementation and testing of the

Foldable Rotary Origami Wing (FROW) drone. The performance evaluation focuses

on the mechanical integrity of the origami wing, the efficiency of the active morphing

mechanism, and the drone's ability to achieve lift-off under varied configurations. The

observations, performance metrics, and mechanical challenges encountered during the

experimental phase are discussed in detail.

### 6.1 TEST RESULTS

After the physical prototype was assembled and the Raspberry Pi Pico-based control

logic was uploaded, the system underwent a series of ground-based and lift-off tests.

These tests were crucial to verify how the origami wing behaves under high-speed

rotation and how the drone responds to physical geometry changes.

### 6.1.1 Test Conditions

To assess the robustness of the FROW system, testing was conducted under the

following conditions:

- Stationary Rotational Tests: Conducted to measure centrifugal expansion

thresholds.

- Active Morphing Duty Cycles: Repeated folding and unfolding via the servo-

string mechanism to test material fatigue.

- Ground-to-Lift Transitions: Conducted on low-friction surfaces to evaluate

initial aerodynamic lift generation.

- Variable Throttle Ramp-ups: Testing the 0.05-step software ramping logic to

ensure structural stability.

### 6.1.2 Performance Metrics and Observations

The key performance indicators recorded during testing were:

- Footprint Reduction:
1. The system successfully reduced its effective wingspan from 750 mm to

450 mm.

2. This represents a 40% reduction in footprint, validating the drone's

ability to navigate restricted passages.

- Lift Efficiency:
1. The system achieved a lift-to-power ratio of 7.1 g/W.
2. This significantly outperformed standard multicopter benchmarks (~4.3

g/W), confirming the aerodynamic superiority of the monocopter

design.

- Actuation Speed:
1. The active folding sequence was completed in approximately 0.8 to 3

seconds depending on the servo power settings.

2. Wing expansion occurred near-instantaneously once string tension was

released, driven by centrifugal forces.

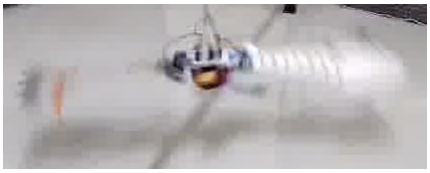
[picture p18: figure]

Figure 6.1: Unfolded FROW Rotation

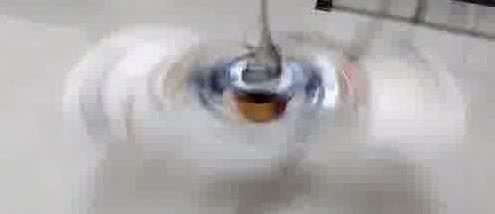
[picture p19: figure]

Figure 6.2: Folded FROW Rotation

### 6.2 DISCUSSION

The testing phase of the Foldable Rotary Origami Wing (FROW) drone was conducted

to evaluate its flight performance, stability, and in-flight morphing capability.

Experimental analysis was performed in both expanded and folded wing configurations

to study lift generation, angular momentum effects, and structural behavior during

flight.

### 6.2.1 Morphing Performance Analysis

During testing, the drone demonstrated the ability to lift itself from the ground,

confirming that the balsa-wood origami wing generates sufficient lift even in its

partially contracted state. A significant observation was the conservation of angular

momentum: as the wings folded, the rotational speed (Ωz

) increased. While this

behavior supports high-speed maneuverability, it also introduces precession

(wobbling), which currently requires manual throttle adjustment by the operator to

maintain stable and level flight.

The "Expanded" state proved most stable for hovering, while the "Folded" state

increased agility but reduced the passive stability inherited from the samara seed design.

### 6.2.2 Challenges Faced

Several mechanical and software challenges were encountered during the testing phase:

- Mechanical Binding: The 3D-printed wing hanger supports initially

experienced friction against the carbon fiber rods. This was resolved by

applying dry lubricant and refining the internal diameter of the printed sliders.

- Lamination Memory: The polymer film used for the "living hinges"

occasionally resisted full expansion in low-temperature environments.

Applying heat-setting techniques to the creases improved the wing's

deployment consistency.

- Moment of Inertia Shifting: The sudden shift in mass during morphing created

high-frequency vibrations. The MicroPython-based safety clamps and ramping

logic were essential in preventing these vibrations from leading to structural

failure.

## CHAPTER 7

## CONCLUSION AND FUTURE WORK

### 7.1 CONCLUSION

The proposed solution for tackling the challenges faced by traditional drones due to

their rigid structure is the creation of the FROW drone. With the incorporation of the

active accordion origami design to the monocopter design, it has been achieved that the

wingspan of the drone can be reduced by about 40% in flight, which results in a span

change from 750 mm to 450 mm. Thus, the drone is capable of switching between its

optimal efficiency flying mode to a compact mode that facilitates it to maneuver

through confined spaces, like pipelines, tunnels, or collapsed buildings. The design uses

light materials such as balsa wood and polymer sheets to form its structural frame,

which provides enough stiffness to maintain stability at high speeds of rotation while

remaining flexible enough to fold. The onboard controller, consisting of the Raspberry

Pi Pico W, efficiently handles the dynamic changes in the shape and position of the

rotating body with specific algorithms of stabilizing and cyclic thrust controls. The

addition of the web interface also helps in improving the performance of the drone

through wireless remote controlling, parameter tuning, and device managing functions

through WiFi connection.

Experimental results demonstrate that the FROW drone can successfully lift its own

weight and actuate its morphing sequence mid-air. The platform achieved a measured

flight efficiency of 7.1 g/W, significantly outperforming traditional multicopters and

validating the aerodynamic advantages of the monocopter design. The successful

implementation of this prototype marks a significant step toward a more adaptable and

inclusive aerial robotics infrastructure.

Overall, the integration of active origami morphing into rotary-wing platforms

contributes substantially to the broader goal of resilient robotics by ensuring that

collision footprints do not hinder mission success in cluttered environments. This

unified framework provides a foundation for a more accessible and agile micro-aerial

ecosystem, fostering innovative engineering solutions for search-and-rescue and

industrial inspection in the digital age.

### 7.2 ADVANTAGES

The proposed FROW drone system offers several key advantages:

- In-Flight Adaptability: The system is designed to reduce its effective wingspan

instantaneously, providing immediate footprint reduction upon command. This

capability is critical for navigating narrow gaps smaller than the original wingspan

without stopping or landing.

- Superior Power Efficiency: By utilizing a single-actuator monocopter design, the

drone maximizes its lift-to-power ratio. This efficiency allows for extended operation

times on standard consumer batteries compared to high-drain quadrotor configurations.

- Mechanical Resilience: The use of origami living hinges and laminated balsa wood

provides a high degree of durability. The structure can withstand the centrifugal stresses

of rotation while remaining resilient against minor impacts, which is essential for close-

quarters operation.

- Low Actuator Count: The adaptable architecture achieves complex flight control

with fewer motors and servos than traditional drones. This reduces potential points of

failure and lowers the overall hardware cost for deployment in low-resource settings.

- Scalable Control: The modular design of the MicroPython firmware and cloud-based

backend facilitates easy expansion. New flight modes or safety features can be

incorporated seamlessly without necessitating substantial modifications to the core

hardware.

### 7.3 LIMITATIONS

- Manual Stability Correction: The current prototype requires manual throttle

adjustment to compensate for precession and wobbling during wing folding operations.

This limits the ability of the drone to maintain completely stable autonomous flight

under all operating conditions.

- Limited Autonomous Control: The system does not yet incorporate advanced

autonomous flight stabilization algorithms or closed-loop feedback control for fully

independent operation during morphing maneuvers.

- Structural Wear Over Time: The origami-inspired folding mechanism and

lightweight balsa wood structure may experience material fatigue, hinge wear, or

deformation after repeated folding and high-speed rotational cycles.

- Communication Latency: The drone currently relies on WiFi-based HTTP communication between the frontend, backend, and Raspberry Pi Pico W. This may

introduce response delays when compared to dedicated low-latency RF communication

systems used in conventional UAVs.

- Restricted Payload Capacity: Due to the lightweight monocopter configuration and

single-rotor propulsion architecture, the drone can support only limited payload weight

while maintaining stable flight performance.

- Environmental Sensitivity: External disturbances such as wind, uneven airflow, and

sudden rotational imbalance can significantly affect the stability of the drone because

of its lightweight rotating structure.

- Limited Flight Testing: The prototype has primarily undergone controlled ground

and tethered testing, and extensive outdoor validation under real-world environmental

conditions is still required.

- Complex Dynamic Behavior: Variations in moment of inertia during wing folding

can introduce rapid changes in rotational dynamics, making stabilization and control

more challenging during transition states.

### 7.4 APPLICATIONS

The FROW drone system has a wide range of potential applications:

- Search and Rescue: The ability to shrink the wingspan mid-flight makes this drone

ideal for entering rubble or narrow cavities in disaster zones to locate survivors where

traditional drones would be blocked.

- Industrial Inspection: FROW can be adapted for inspecting the internal structures of

pipelines, ventilation shafts, and power plants, offering a hygienic and hands-free

alternative to manual inspection.

- Stealth Surveillance: Reducing the footprint in flight lowers the visual and radar

cross-section of the vehicle, facilitating "stealthy" approaches for sensitive monitoring

tasks.

- Environmental Monitoring: The high power efficiency of the monocopter platform

allows for longer-duration monitoring of dense forest canopies or restricted wildlife

habitats.

- Assistive Infrastructure: This technology can empower teams to deploy sensor

networks in hazardous areas by navigating through complex scaffolding or industrial

frameworks that lack clear flight paths.

### 7.5 FUTURE ENHANCEMENTS

There are numerous opportunities for improving the system's capabilities and

expanding its versatility:

- Autonomous Stability and PID Tuning: Future versions will integrate more

sophisticated adaptive PID controllers to automatically compensate for shifting

mass during morphing, ensuring a perfectly horizontal tip-path plane without

operator intervention.

- Autonomous Gap Detection: The integration of lightweight Time-of-Flight

(ToF) sensors or a mini-camera would allow the drone to detect narrow

openings and trigger the wing-fold sequence automatically.

- Passive Diving Mechanism: Implementing a reverse-thrust command logic

would enable the drone to execute actuator-free high-speed dives, mimicking

the behavior of predatory birds for rapid descent.

- Multi-Wing Configurations: Exploring modular hubs that can support

multiple origami wings would improve lift capacity and allow for more complex

multi-user or team-based heavy-lifting scenarios.

- Augmented Reality (AR) Integration: Combining real-time telemetry from

the Raspberry Pi Pico with AR platforms could allow users to control the

drone’s morphing state through immersive 3D gestures or virtual menus for

remote assistance.

## REFERENCES

[1] H. Bhardwaj, X. Cai, L. S. T. Win, and S. Foong, “Nature-inspired in-flight foldable

rotorcraft,” Bioinspiration & Biomimetics, vol. 18, no. 4, art. 046012, 2023. DOI:

10.1088/1748-3190/acd739.

[2] S. K. H. Win, L. S. T. Win, D. Sufiyan, and S. Foong, “Design and control of the

first foldable single-actuator rotary wing micro aerial vehicle,” Bioinspiration &

Biomimetics, vol. 16, no. 6, art. 066019, 2021. DOI: 10.1088/1748-3190/ac253a.

[3] M. Li, “Beyond Conventional Drones: A Review of Unconventional Rotary-Wing

UAV Design,” Drones, vol. 9, no. 5, art. 323, 2025. DOI: 10.3390/drones9050323.

[4] R. Ishiguro et al., “Earwig-inspired foldable origami wing for micro air vehicle

gliding,” Frontiers in Robotics and AI, vol. 10, art. 1255666, 2023. DOI:

10.3389/frobt.2023.1255666.

[5] Y. Shiferaw et al., “Design and Implementation of Morphed Multi-Rotor Vehicles

with Real-Time Obstacle Detection and Sensing System,” Sensors, vol. 21, no. 18, art.

6192, 2021. DOI: 10.3390/s21186192.

[6] K. Johnson et al., “Solar-powered shape-changing origami microfliers,” Science

Robotics, vol. 8, no. 77, 2023. DOI: 10.1126/scirobotics.ade6725.

[7] Y. Choi et al., “Bioinspired Morphing in Aerodynamics and Hydrodynamics:

Engineering Innovations for Aerospace and Renewable Energy,” Biomimetics, vol. 10,

no. 7, art. 427, 2025. DOI: 10.3390/biomimetics10070427.

[8] O. Acar et al., “Mechanisms and Control Strategies for Morphing Structures in

Quadrotors: A Review and Future Prospects,” Drones, vol. 9, no. 9, art. 663, 2025.

DOI: 10.3390/drones9090663.

[9] P. Tothong et al., “Design and Flight Control of a Symmetrically Morphing

Quadrotor,” IEEE Transactions on Robotics, vol. 38, no. 5, pp. 2680–2695, 2022. DOI:

10.1109/TRO.2022.3160623.

[10] L. S. T. Win, S. K. H. Win, D. Sufiyan, G. S. Soh, and S. Foong, “Achieving

efficient controlled flight with a single actuator,” in 2020 IEEE/ASME International

Conference on Advanced Intelligent Mechatronics (AIM), 2020, pp. 1625–1631. DOI:

10.1109/AIM43001.2020.9158893.

[11] E. R. Ulrich, D. J. Pines, and J. S. Humbert, “From falling to flying: the path to

powered flight of a robotic samara nano air vehicle,” Bioinspiration & Biomimetics,

vol. 5, no. 4, art. 045009, 2010. DOI: 10.1088/1748-3182/5/4/045009.

[12] J. Houghton and W. Hoburg, “Fly-by-wire control of a monocopter,” Project

Report, Massachusetts Institute of Technology, 2008. (No DOI available)

[13] D. Falanga, K. Kleber, S. Mintchev, D. Floreano, and D. Scaramuzza, “The

foldable drone: a morphing quadrotor that can squeeze and fly,” IEEE Robotics and

Automation | Letters, | vol. | 4, | no. | 2, | pp. | 209–216, | 2019. | DOI:

10.1109/LRA.2018.2885575.

[14] S. Bai, Q. He, and P. Chirarattananon, “A bioinspired revolving-wing drone with

passive attitude stability and efficient hovering flight,” Science Robotics, vol. 7, no. 66,

art. eabg5913, 2022. DOI: 10.1126/scirobotics.abg5913.

[15] X. Cai, S. K. H. Win, H. Bhardwaj, and S. Foong, “Modeling, control and

implementation of adaptive reconfigurable rotary wings (ARROWS),” IEEE/ASME

Transactions on Mechatronics, 2023. DOI: 10.1109/TMECH.2023.3235346.

## APPENDIX

## Micropython Code

import network

import urequests

import time

import gc

import ujson

from machine import Pin, PWM

# ---------------- WIFI ----------------

ssid = "your_ssid"

password = "your_password"

wlan = network.WLAN(network.STA_IF)

wlan.active(True)

wlan.connect(ssid, password)

while not wlan.isconnected():

print("Connecting...")

time.sleep(1)

print("Connected:", wlan.ifconfig())

BASE_URL = "https://trial-web-1.onrender.com"

# ---------------- PWM SETUP ----------------

servo1 = PWM(Pin(14))

servo2 = PWM(Pin(15))

esc = PWM(Pin(16))

for p in (servo1, servo2, esc):

p.freq(50)

def set_pulse(pwm, pulse_ms):

duty = int((pulse_ms / 20) * 65535)

pwm.duty_u16(duty)

# ---------------- INITIAL ----------------

set_pulse(esc, 1.0)

time.sleep(3)

# ---------------- FLAGS ----------------

motor_running = False

servo_done = False

# ---------------- MAIN LOOP ----------------

while True:

try:

res = urequests.get(BASE_URL + "/state")

text = res.text

res.close()

data = ujson.loads(text)

power = data.get("power")

servo_cmd = data.get("servo")

motor_data = data.get("motor", {})

motor_power = motor_data.get("power")

hold_time = motor_data.get("holdTime", 3)

max_pulse = motor_data.get("maxPulse", 1.3)

# -------- SAFETY CLAMP --------

if max_pulse > 1.5:

max_pulse = 1.5

if max_pulse < 1.1:

max_pulse = 1.1

# -------- POWER OFF --------

if power == "OFF":

print("Power OFF")

set_pulse(esc, 1.0)

motor_running = False

servo_done = False

time.sleep(1)

continue

# -------- POWER ON --------

if power == "ON":

# -------- SERVO --------

if servo_cmd == "FOLD" and not servo_done:

print("Servo folding...")

set_pulse(servo1, 1.3)

set_pulse(servo2, 1.3)

time.sleep(3.8)

set_pulse(servo1, 1.5)

set_pulse(servo2, 1.5)

servo_done = True

try:

r = urequests.post(BASE_URL + "/reset-servo")

r.close()

except:

pass

# -------- MOTOR --------

if motor_power == "ON" and not motor_running:

print("Motor START")

print("Max Pulse:", max_pulse)

motor_running = True

# ---- RAMP UP (0.05 step) ----

val = 1.0

while val <= max_pulse:

set_pulse(esc, round(val, 2))

val += 0.05

time.sleep(0.5)

# ---- HOLD ----

print("Holding for", hold_time)

set_pulse(esc, max_pulse)

time.sleep(hold_time)

# ---- RAMP DOWN (0.05 step) ----

val = max_pulse

while val >= 1.0:

set_pulse(esc, round(val, 2))

val -= 0.05

time.sleep(0.5)

set_pulse(esc, 1.0)

motor_running = False

# -------- UPDATE BACKEND --------

try:

r = urequests.post(

BASE_URL + "/motor",

headers={"Content-Type": "application/json"},

data=ujson.dumps({

"power": "OFF",

"holdTime": hold_time,

"maxPulse": max_pulse

})

)

r.close()

print("Motor OFF updated")

except Exception as e:

print("Backend error:", e)

gc.collect()

time.sleep(0.5)

except Exception as e:

print("Error:", e)

gc.collect()

time.sleep(2)

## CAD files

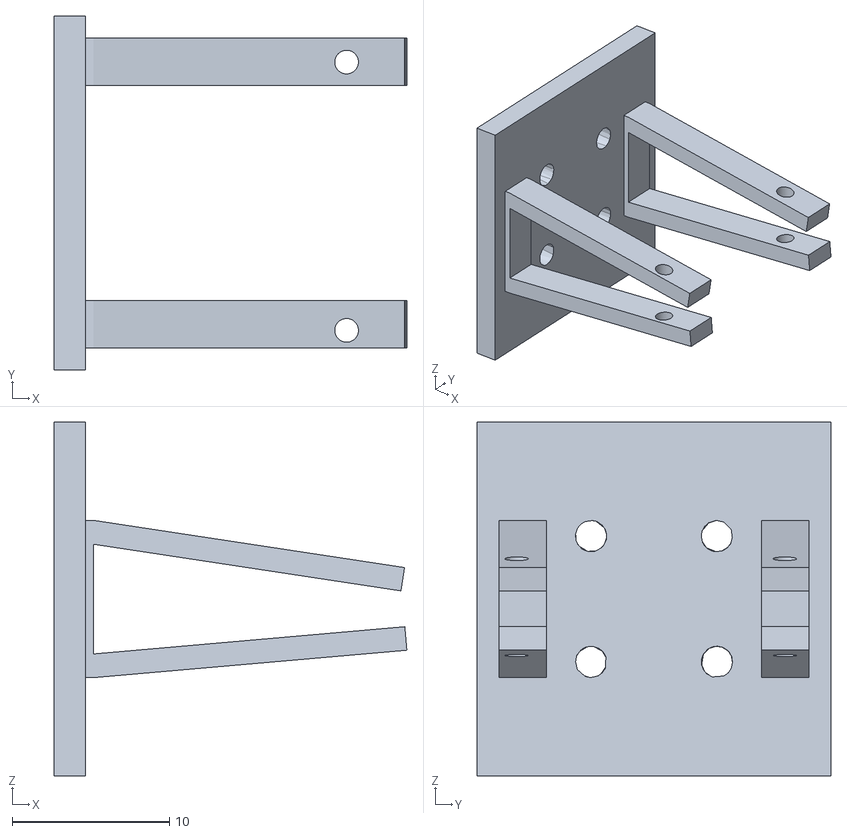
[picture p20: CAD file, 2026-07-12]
3D Design/Motor Holder.stl
22.4 x 22.5 x 22.5

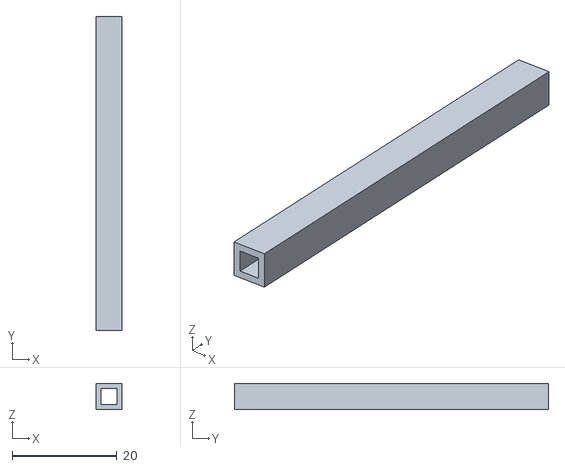
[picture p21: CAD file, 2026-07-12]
3D Design/Carbon fiber holder.stl
5.00 x 60.0 x 5.00

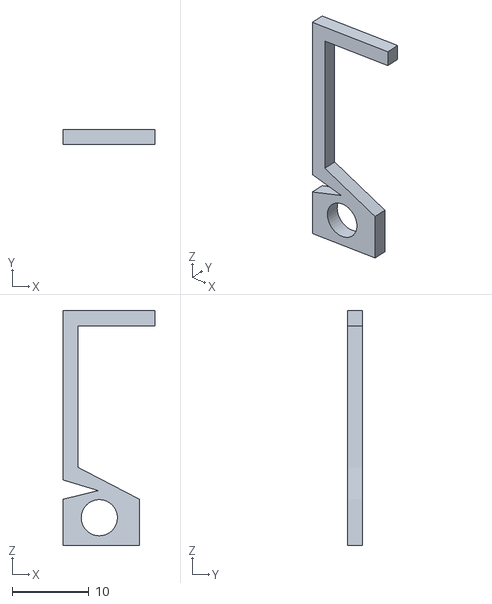
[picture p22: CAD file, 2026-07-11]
3D Design/Hinge updated.STL
12.0 x 2.00 x 30.5

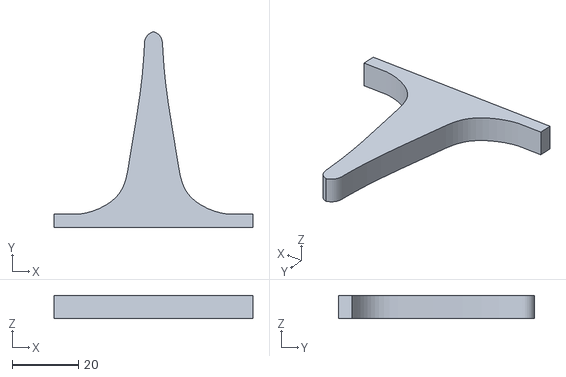
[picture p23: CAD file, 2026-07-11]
3D Design/Wing stand.STL
60.0 x 59.0 x 7.00

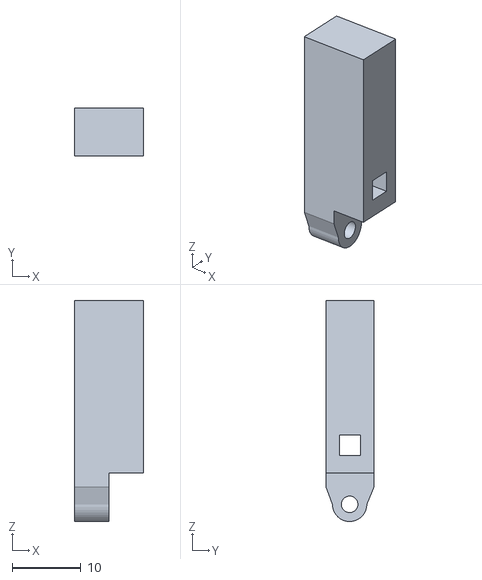
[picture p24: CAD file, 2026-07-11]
3D Design/U Pin Holder.STL
10.0 x 7.00 x 32.0

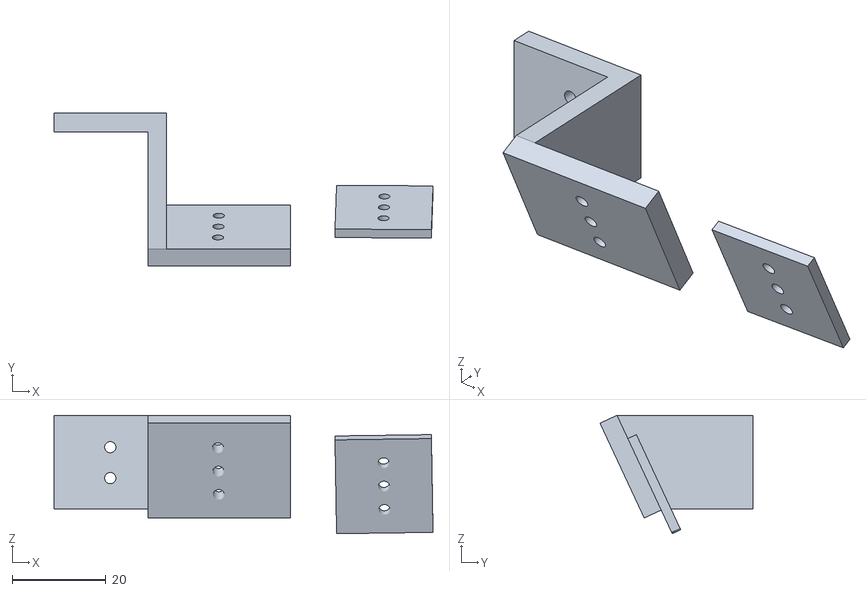
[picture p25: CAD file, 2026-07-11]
3D Design/wing holder updated.STL
80.8 x 32.6 x 25.2

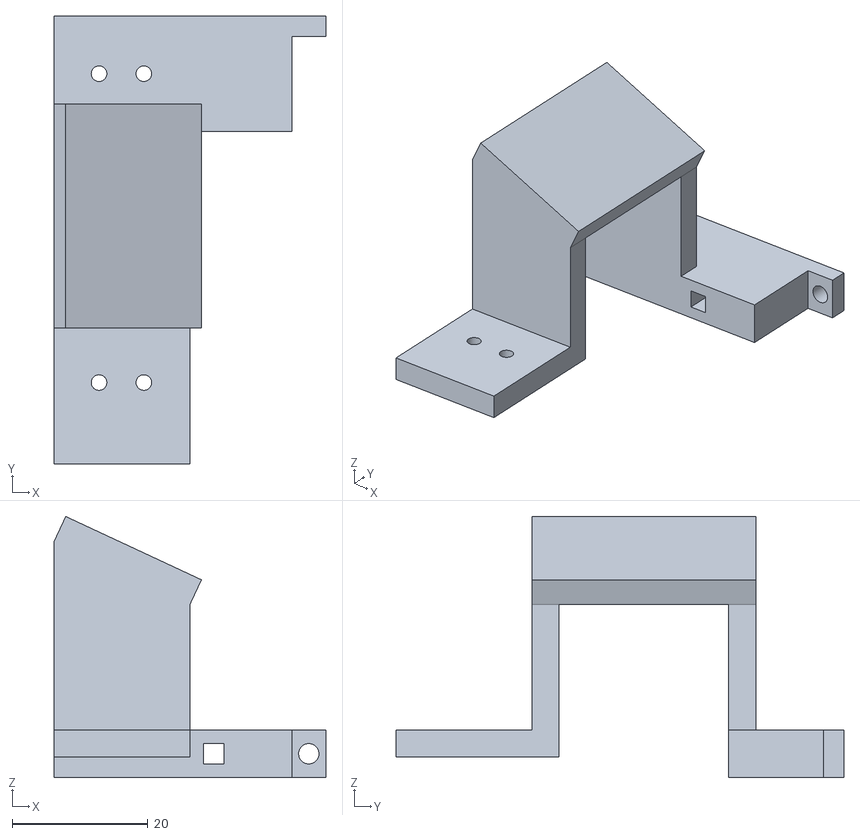
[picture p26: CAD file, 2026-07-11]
3D Design/Servo holding slanted.STL
40.0 x 66.0 x 38.5

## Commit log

2026-07-11 Raspberry Pi Pico W Code
2026-07-11 3D Design/
    [Carbon fiber stopper.STL, Hinge updated.STL, Motor Holder new.STL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]
2026-07-12 Custom 3D Design file
    [Carbon fiber holder.stl, Hinge updated.STL, Motor Holder.stl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]
2026-07-12 Add README for Foldable Rotary Origami Wing Drone
    Added comprehensive project details for the Foldable Rotary Origami Wing Drone, including features, repository structure, hardware and software used, working principle, and future improvements.
